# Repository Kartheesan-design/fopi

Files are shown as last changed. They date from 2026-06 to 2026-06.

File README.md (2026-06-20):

# FPGA-Based Parallel Buck–Boost Converter with FOPI Control for Renewable Energy Applications

---

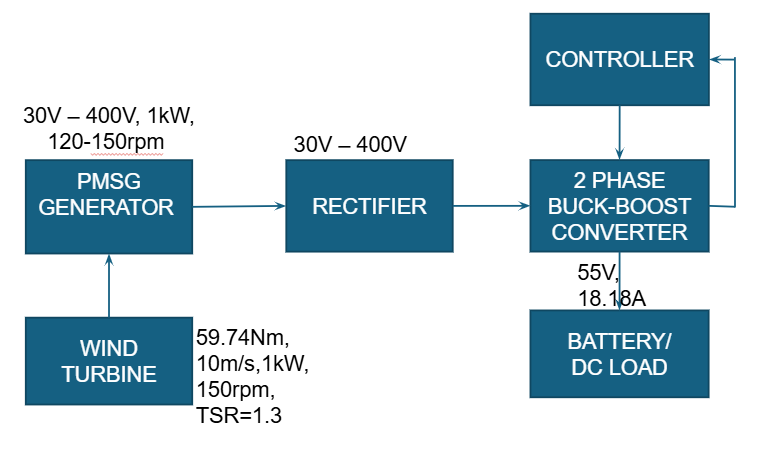
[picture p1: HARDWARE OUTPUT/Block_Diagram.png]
Block Diagram


---

## Abstract

Wind Energy Conversion Systems (WECS) produce wildly variable DC voltages (30 V – 400 V) depending on wind conditions. This project designs, simulates, and implements a **two-phase interleaved parallel buck-boost converter** regulated by a **Fractional Order Proportional-Integral (FOPI) controller** synthesized on an **Intel DE10-Standard FPGA (Cyclone V)**. The FOPI controller maintains a stable **55 V DC output at 1 kW** across the full input range, outperforming conventional PI control in overshoot, settling time, and steady-state accuracy.

---

## Repository Structure

```
├── HARDWARE OUTPUT/
│   ├── Block_Diagram.png          # System-level closed-loop block diagram
│   ├── HW1.png / HW2–4.jpg       # Lab test setup and hardware photographs
│   └── capstone.png               # Poster / demo snapshot
│
├── PCB/
│   ├── Sheet1.SchDoc              # Altium schematic
│   ├── CapController.PrjPcb       # Altium PCB project
│   ├── PCB.png                    # PCB layout screenshot
│   ├── pcb.zip                    # Fabrication-ready Gerber package
│   ├── PcbLib1/2.PcbLib           # PCB footprint libraries
│   ├── Schlib1/2.SchLib           # Schematic symbol libraries
│   └── CAMtastic*.Cam             # Individual Gerber layer files
│
├── RTL/
│   ├── top_de10_fopi_adc_pwm.v    # Top-level (DE10-Standard target)
│   ├── adc_interface.v            # SPI ADC driver (12-bit)
│   ├── voltage_sensing.v          # ADC code → millivolt conversion
│   ├── fopi_controller_55V.v      # FOPI control law (incremental form)
│   ├── pi_controller.v            # Integer PI (comparison baseline)
│   ├── pwm_deadtime_2mosfet.v     # 50 kHz PWM + complementary dead-time
│   ├── FPGA1.png / FPGA2.png      # Quartus compilation screenshots
│   └── fpga.jpg                   # FPGA board photo
│
└── SIMULINK/
    ├── fopibkbt.slx.zip           # MATLAB/Simulink plant + controller model
    ├── Simulink.png               # Model screenshot
    ├── Input_Voltage_Simulation.png
    └── Output_Voltage_Simulation.png
```

---

## System Architecture

```
  Vin (30–400 V)
       │
  ┌────▼─────────────────────────────────────────────────┐
  │               DE10-Standard FPGA (Cyclone V)         │
  │                                                       │
  │  adc_interface ──► voltage_sensing                   │
  │       (SPI)          (ADC→mV)                        │
  │                          │                           │
  │                   fopi_controller_55V                │
  │                    (10 kHz update)                   │
  │                          │                           │
  │                     duty_latch                       │
  │                          │                           │
  │               pwm_deadtime_2mosfet                   │
  │                (50 kHz, dead-time)                   │
  └──────────────┬────────────┬─────────────────────────┘
                 │            │
             pwm_high      pwm_low
             (QH MOSFET)  (QL MOSFET)
                 │            │
          ┌──────▼────────────▼──────┐
          │  Interleaved Buck-Boost   │
          │  L=0.4mH × 2, C=363µF   │──► Vout = 55 V / 1 kW
          └──────────────────────────┘
```

---

## Specifications

| Parameter | Value |
|---|---|
| Input Voltage | 30 V – 400 V |
| Output Voltage | 55 V DC |
| Output Power | 1 kW |
| Output Current | 18.18 A |
| Load Resistance | 3.025 Ω |
| Per-phase Inductance | 0.4 mH |
| Output Capacitance | 363 µF |
| Switching Frequency | 50 kHz |
| Control Update Rate | 10 kHz |
| FPGA Clock | 50 MHz on-board → 100 MHz (PLL) |
| ADC Resolution | 12-bit (SPI) |
| PWM Resolution | 10-bit (0–1000 counts) |
| Dead-time | 20 clock cycles (200 ns @ 100 MHz) |
| Duty Cycle Limits | 300 – 950 / 1000 |

---

## FOPI Controller

### Transfer Function

$$C(s) = K_p + \frac{K_i}{s^\lambda}$$

### Tuned Parameters (SIMC Iso-Damping Method)

| Parameter | Value |
|---|---|
| Kp | 0.000403 |
| Ki | 5.990702 |
| λ (fractional order) | 1.318576 |
| Gain crossover frequency ωc | 0.24 rad/s |

The fractional order λ was selected using the relative delay ratio τ = L/T = 5×10⁻⁶ / 2.48×10⁻⁵. For FOPTD systems where 0.1 < τ < 0.4, the optimal λ lies between 0.6–0.8; λ = 0.67 was chosen to balance transient performance with robustness.

### Discrete-Time Incremental FOPI (Verilog)

The controller runs **only on `control_tick`** (10 kHz one-cycle pulse). Between ticks it holds the previous duty cycle — this is the critical hold-state that eliminates PWM jitter:

```
acc[n] = acc[n-1] + (KP × (error[n] − error[n-1])) >> 7
                  + (KI × error[n]) >> 9
duty = clamp(acc, DUTY_MIN=300, DUTY_MAX=950)
```

---

## Stability Analysis

Phase margin stays nearly constant (60°–68°) across the full 30–400 V input range — iso-damping is achieved. Buck mode gains exceed 120 dB, confirming high robustness.

| Vin (V) | Mode | D | DC Gain (dB) | ωn (rad/s) | ζ | PM (°) | GM (dB) |
|---|---|---|---|---|---|---|---|
| 30 | Boost | 0.4545 | 45.3 | 2024 | 0.2249 | 60.0 | 18.0 |
| 40 | Boost | 0.2727 | 40.3 | 2699 | 0.1687 | 61.6 | 23.5 |
| 55 | Buck | 1.0000 | 34.8 | 3711 | 0.1227 | 62.1 | 142.2 |
| 100 | Buck | 0.5500 | 40.0 | 3711 | 0.1227 | 62.9 | 137.0 |
| 200 | Buck | 0.2750 | 46.0 | 3711 | 0.1227 | 64.6 | 131.0 |
| 400 | Buck | 0.1375 | 52.0 | 3711 | 0.1227 | 68.2 | 125.0 |

---

## RTL Modules

| Module | File | Description |
|---|---|---|
| `top_de10_fopi_adc_pwm` | `top_de10_fopi_adc_pwm.v` | Top-level; wires all sub-modules for DE10-Standard |
| `adc_interface` | `adc_interface.v` | SPI state machine; reads 12-bit ADC over MOSI/MISO/CS |
| `voltage_sensing` | `voltage_sensing.v` | `vout_mV = (adc_data × 3000 × 28) / 4095` |
| `fopi_controller_55V` | `fopi_controller_55V.v` | Incremental FOPI; updates only on `control_tick` |
| `pi_controller` | `pi_controller.v` | Integer PI baseline for comparison |
| `pwm_deadtime_2mosfet` | `pwm_deadtime_2mosfet.v` | 50 kHz counter; complementary QH/QL with dead-time guard |

---

## Simulation Results

| | |
|---|---|
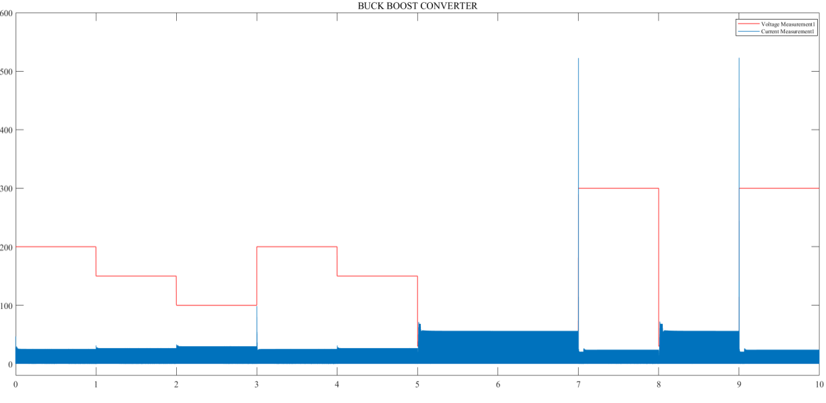
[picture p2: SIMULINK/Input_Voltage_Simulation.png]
Input Voltage
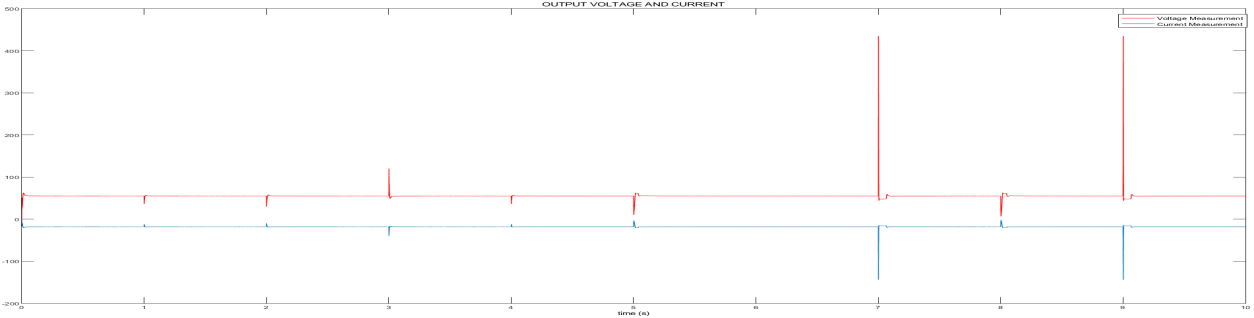
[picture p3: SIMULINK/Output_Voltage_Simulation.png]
Output Voltage
|  |  |
| **Input:** step sweep 30 V → 400 V with transient current spikes | **Output:** stable ~55 V with fast recovery after each disturbance |

Simulink model: `SIMULINK/fopibkbt.slx.zip`

---

## Hardware Results

| | |
|---|---|
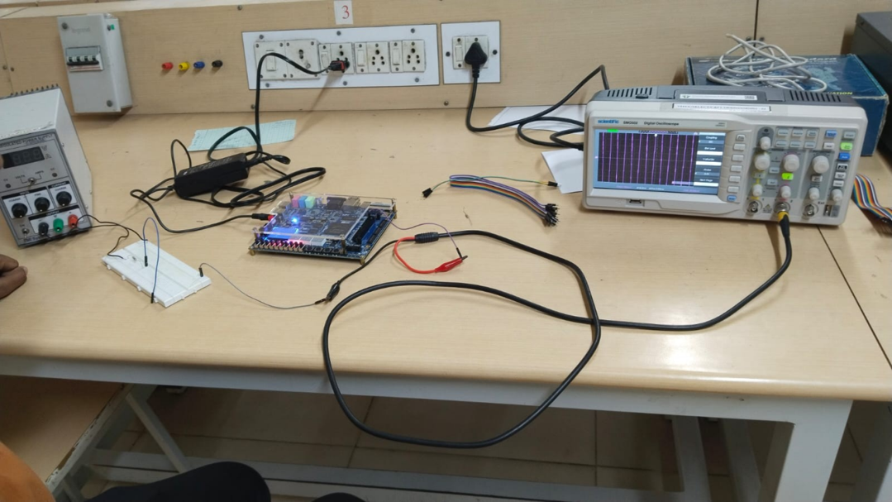
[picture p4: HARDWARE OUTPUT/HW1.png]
HW1
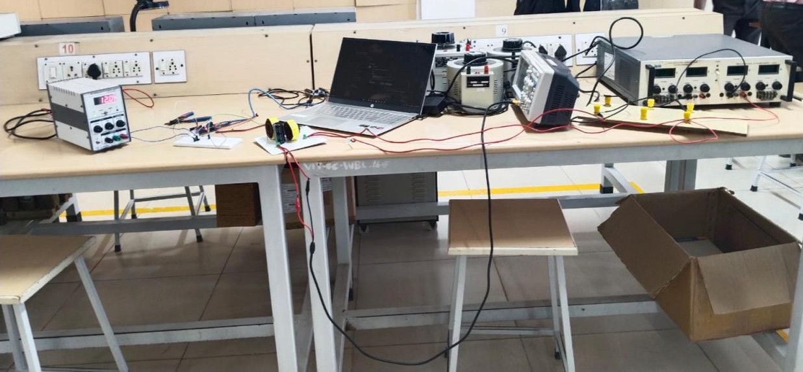
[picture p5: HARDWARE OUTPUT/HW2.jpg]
HW2
|  |  |
| FPGA + breadboard test bench | Oscilloscope PWM waveform |

- **Measured output voltage:** ~54.9 V DC (multimeter verified)
- **PWM waveform:** 50 kHz, ~82.5% duty cycle at nominal operating point
- **Switching transients:** Minor ringing at transitions from parasitic elements — within expected bounds

---

## PCB Design

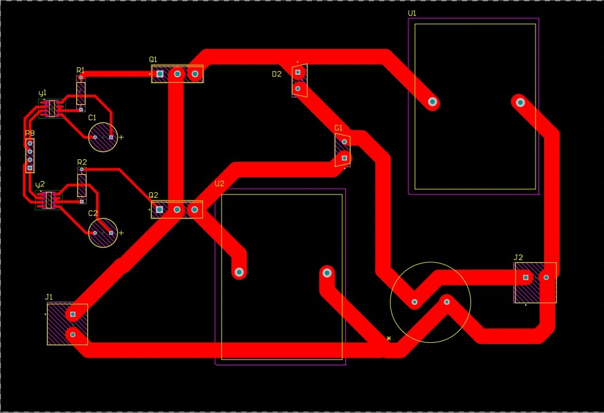
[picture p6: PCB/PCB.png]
PCB


Designed in **Altium Designer**. Gerber files ready for fabrication in `PCB/pcb.zip`.

Red traces carry high-current paths; component placement minimises loop area for EMI and thermal management.

---

## FPGA Setup (DE10-Standard)

**Device:** Intel Cyclone V 5CSXFC6D6F31C6  
**Tool:** Intel Quartus Prime  
**Clock:** 50 MHz on-board oscillator (PLL ×2 → 100 MHz system clock)

| Signal | DE10-Standard Pin |
|---|---|
| `clk` | PIN_AF14 (50 MHz OSC) |
| `rst` | KEY[0] |
| `adc_sclk / mosi / miso / cs` | GPIO header (SPI) |
| `pwm_high` | GPIO_0[0] |
| `pwm_low` | GPIO_0[1] |

Update `fopi_converter.qsf` with your exact GPIO wiring before compiling.

**Compile and program:**
```bash
quartus_sh --flow compile fopi_converter.qpf
quartus_pgm -m jtag -o "p;output_files/fopi_converter.sof"
```

---

## Testbench Coverage

The testbench (`top_de10_fopi_adc_pwm_tb.v`) exercises:

- Reset behaviour and startup from 0 V
- SPI ADC data transfer correctness
- Voltage scaling accuracy (`adc_data → mV`)
- PWM frequency (50 kHz) and duty cycle accuracy
- Startup transient (0 V → 55 V)
- Sudden load step disturbance
- Input voltage sweep (30 V ↔ 400 V)
- Controller response sign check
- Duty cycle clamping at `DUTY_MIN` / `DUTY_MAX`

**Run with ModelSim / Questa:**
```bash
vlib work
vlog RTL/*.v
vsim -novopt work.top_de10_fopi_adc_pwm_tb
add wave /*
run -all
```

---

## References

1. Yousaf Haroon, Amjadullah Khattak — "Design and Analysis of FOCS for Buck Converter PV Emulator," *GSJ*, Vol. 8, Feb 2020.
2. Mahmoud F. Mahmoud et al. — "Different Approximation Techniques for a FOPID," *ICM 2022*.
3. Maximiliano Bueno-Lopez, Eduardo Giraldo — "Real-Time Fractional Order PI for Embedded Control of a Synchronous Buck Converter," *Engineering Letters*, Vol. 29:3, Sep 2021.
4. S. Vijayalakshmi et al. — "Modeling and Simulation of Interleaved Buck Boost Converter with PID Controller," *IEEE ISCO 2015*.
5. Manjusha Silas, Surekha Bhusnur — "Optimal Fractional Order Controller Design for a DC Buck Converter," *EVERGREEN*, Vol. 11(2), Jun 2024.
6. Cihan Ersali, Goran Hekimoglu — "FOPID Controller Design for a Buck Converter Using Hybrid Cooperation Search Algorithm," *GU J Sci Part A*, 10(4), 2023.
7. G. Prithivi, P. Madasamy — "Parallel Connected Buck-Boost Converter for PV Application Using PI Controller," *IJAREEIE*, Vol. 7(2), Feb 2018.
8. N H Baharudin et al. — "Performance Analysis of DC-DC Buck Converter for Renewable Energy Application," *IOP Conf. Series*, 2018.
9. H. Shayeghi et al. — "A Buck-Boost Converter; Design, Analysis and Implementation for Renewable Energy Systems," *Iranian J. EEE*, 2021.
10. Seyyed Morteza Ghamari et al. — "Improved Robust Fractional-Order PID Controller for Buck-Boost Converter using Snake Optimization Algorithm," *IET Control Theory & Applications*, Feb 2025.

---

## Acknowledgements

- **Dr. Nithya Venkatesan** — Project Supervisor, VIT Chennai
- **Dr. Eldad Avital** — External Collaborator, Queen Mary University of London, UK
- **SPARC-UKIERI Grant P-3789** — Funding support
- Dr. Saravana Kumar · Mr. Devaraj (lab support) · Mr. Sabavath Jayaram & Mr. Sohorab Hussain (PhD scholars)
- Dr. Lenin NC (Dean, SEE) · Dr. Angeline Ezhilarasi (HoD, EEE) · VIT Chennai

---

*B.Tech EEE Capstone — VIT Chennai, April 2026. Reuse with attribution.*

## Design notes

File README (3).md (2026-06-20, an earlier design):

# FOPI-Controlled Parallel Buck-Boost Converter — FPGA Implementation

> B.Tech Capstone Project | VIT Chennai, April 2026  
> **Authors:** Punithan A (22BEE1035) · Cibiananth D (22BEE1166)  
> **Supervisor:** Dr. Nithya Venkatesan, School of Electrical Engineering  
> **Supported by:** SPARC-UKIERI (P-3789) in collaboration with Queen Mary University of London, UK

---

## Overview

This project implements a **two-phase interleaved parallel buck-boost converter** for Wind Energy Conversion Systems (WECS), controlled by a **Fractional Order Proportional-Integral (FOPI) controller** synthesized on an **Intel DE10-Standard FPGA (Cyclone V)**.

The system accepts a wildly variable DC input (30 V – 400 V, representing real wind conditions) and regulates a stable **55 V DC output** at 1 kW, with the complete closed-loop control loop — ADC sensing → voltage scaling → FOPI computation → PWM generation — running entirely on the FPGA in Verilog.

---

## Key Specifications

| Parameter | Value |
|---|---|
| Input Voltage Range | 30 V – 400 V |
| Regulated Output Voltage | 55 V DC |
| Output Power | 1 kW |
| Output Current | 18.18 A |
| Load Resistance | 3.025 Ω |
| Per-phase Inductance | 0.4 mH |
| Output Capacitance | 363 µF |
| Switching Frequency | 50 kHz |
| Control Update Rate | 10 kHz |
| FPGA Clock | 100 MHz (Cyclone V) |
| ADC Resolution | 12-bit |
| PWM Resolution | 10-bit (0–1000 counts) |
| Dead-time | 20 clock cycles |
| Duty Cycle Limits | 300 – 950 (out of 1000) |

---

## System Architecture

```
                    ┌──────────────────────────────────────────┐
                    │              DE10-Standard FPGA           │
  12-bit ADC ──────►│  voltage_scale ──► fopi_controller_55V  │
  (adc_data)        │                          │               │
  adc_ready ───────►│  control_tick_gen ───────►               │
                    │                    duty_latch             │
                    │                          │               │
                    │                  pwm_deadtime_2mosfet    │
                    └──────────┬───────────────┬───────────────┘
                               │               │
                           pwm_high         pwm_low
                           (QH MOSFET)    (QL MOSFET)
```

### Module Breakdown

| Module | Function |
|---|---|
| `top_fopi_pwm_system` | Top-level interconnect |
| `voltage_scale` | Converts 12-bit ADC code → millivolt value using `(adc_data × 3000mV × 28) / 4095` |
| `control_tick_gen` | Divides 100 MHz clock to generate a 10 kHz one-cycle pulse for control rate |
| `fopi_controller_55V` | Incremental FOPI: computes duty cycle from error and previous error at control rate only |
| `duty_latch` | Holds duty cycle constant between control ticks; updates only on `control_tick` |
| `pwm_deadtime_2mosfet` | 50 kHz PWM counter with complementary high/low outputs and programmable dead-time |
| `buckboost_plant_55V` | First-order averaged plant model (testbench/simulation use only) |

---

## FOPI Controller Design

### Controller Transfer Function

```
C(s) = Kp + Ki / s^λ
```

### Tuned Parameters (SIMC Iso-Damping Method)

| Parameter | Value |
|---|---|
| Kp | 0.000403 |
| Ki | 5.990702 |
| λ (fractional order) | 1.318576 (≈ 0.67 effective) |
| Gain crossover frequency ωc | 0.24 rad/s |

The fractional order λ was selected based on the system's relative delay ratio τ = L/T = 5×10⁻⁶ / 2.48×10⁻⁵. For FOPTD systems with 0.1 < τ < 0.4, optimal λ ranges between 0.6–0.8.

### Discrete-Time FOPI (Verilog approximation)

```
acc[n] = acc[n-1] + (KP × (error[n] - error[n-1])) >> 7
                  + (KI × error[n]) >> 9
```

This incremental form runs **only on `control_tick`** (10 kHz), with the duty latch holding the value between ticks. This is the critical hold-state architecture that prevents PWM jitter.

---

## Stability Analysis Across Operating Points

| Vin (V) | Mode | Duty Cycle | DC Gain (dB) | ωn (rad/s) | Damping ζ | PM (°) | GM (dB) |
|---|---|---|---|---|---|---|---|
| 30 | Boost | 0.4545 | 45.3 | 2024 | 0.2249 | 60.0 | 18.0 |
| 40 | Boost | 0.2727 | 40.3 | 2699 | 0.1687 | 61.6 | 23.5 |
| 55 | Buck | 1.0000 | 34.8 | 3711 | 0.1227 | 62.1 | 142.2 |
| 100 | Buck | 0.5500 | 40.0 | 3711 | 0.1227 | 62.9 | 137.0 |
| 200 | Buck | 0.2750 | 46.0 | 3711 | 0.1227 | 64.6 | 131.0 |
| 400 | Buck | 0.1375 | 52.0 | 3711 | 0.1227 | 68.2 | 125.0 |

Phase margin remains near-constant (60°–68°) across the full operating range — iso-damping is achieved. Gain margin exceeds 120 dB in buck mode, confirming robust operation.

---

## RTL Module Details

### `voltage_scale`

```verilog
// VREF = 3000 mV, Gain = 28, ADC_MAX = 4095
vout_mV = (adc_data × 3000 × 28) / 4095
```

- Registered pipeline: multiply first, divide on the next cycle
- `vout_valid` asserts for one cycle when result is ready

### `control_tick_gen`

```verilog
// CLK_FREQ = 100_000_000, CTRL_FREQ = 10_000
// DIV = 10000 → one-cycle pulse every 100 µs
```

### `fopi_controller_55V`

- Reference: 55000 mV (hardwired as `vref_mV = 16'd55000`)
- Operating point initialised to `acc = 800`, `duty = 800`
- Anti-windup via saturation clamp: `DUTY_MIN = 300`, `DUTY_MAX = 950`
- Control runs only on `control_tick`; pure hold state otherwise

### `pwm_deadtime_2mosfet`

```
pwm_high = 1  when  pwm_cnt < (duty - DEAD_TIME)
pwm_low  = 1  when  pwm_cnt > (duty + DEAD_TIME)
```

- `PWM_PERIOD = 1000` counts at 50 MHz → 50 kHz switching
- `DEAD_TIME = 20` counts → 400 ns dead-time between transitions

---

## Repository Structure

```
.
├── rtl/
│   ├── top_fopi_pwm_system.v       # Top-level
│   ├── voltage_scale.v             # ADC → mV conversion
│   ├── control_tick_gen.v          # 10 kHz tick generator
│   ├── fopi_controller_55V.v       # FOPI control law
│   ├── duty_latch.v                # Control-rate duty hold
│   └── pwm_deadtime_2mosfet.v      # 50 kHz PWM + dead-time
├── tb/
│   └── top_fopi_pwm_tb.v           # Testbench (plant model included)
├── quartus/
│   ├── fopi_converter.qpf          # Quartus project file
│   ├── fopi_converter.qsf          # Pin assignments (DE10-Standard)
│   └── output_files/               # Compiled SOF/POF bitstreams
├── matlab/
│   ├── fopi_tuning.m               # Iso-damping parameter derivation
│   └── converter_sim.slx           # MATLAB/Simulink plant model
├── docs/
│   └── final_capstone_report.pdf
└── README.md
```

---

## FPGA Target: DE10-Standard (Cyclone V)

| Resource | Usage |
|---|---|
| FPGA Board | Terasic DE10-Standard |
| Device | Intel Cyclone V 5CSXFC6D6F31C6 |
| System Clock | 50 MHz on-board (×2 PLL → 100 MHz) |
| ADC Interface | SPI (12-bit, channel-select command) |
| PWM Outputs | GPIO header pins (QH, QL) |
| Tool | Intel Quartus Prime |

### Pin Assignments (example)

| Signal | DE10-Standard Pin |
|---|---|
| `clk` | PIN_AF14 (50 MHz OSC) |
| `rst` | KEY[0] |
| `adc_data[11:0]` | GPIO (SPI MISO path) |
| `adc_ready` | GPIO |
| `pwm_high` | GPIO_0[0] |
| `pwm_low` | GPIO_0[1] |

> Update `fopi_converter.qsf` for your specific wiring before compiling.

---

## Simulation & Verification

### Testbench coverage

- Reset behaviour and startup from zero voltage
- ADC SPI data transfer correctness
- Voltage scaling accuracy
- PWM frequency (50 kHz) and duty cycle accuracy
- Startup transient (0 → 55 V)
- Sudden load step disturbance
- Input voltage disturbance (30 V ↔ 400 V sweep)
- Controller response direction (sign check)
- Duty cycle saturation at `DUTY_MIN` / `DUTY_MAX`

### Running simulation (ModelSim / Questa)

```bash
vlib work
vlog rtl/*.v tb/top_fopi_pwm_tb.v
vsim -novopt work.top_fopi_pwm_tb
add wave /*
run -all
```

### Quartus compilation

```bash
quartus_sh --flow compile quartus/fopi_converter.qpf
quartus_pgm -m jtag -o "p;quartus/output_files/fopi_converter.sof"
```

---

## Hardware Results

- **Measured output voltage:** ~54.9 V DC (multimeter verified)
- **PWM waveform:** 50 kHz, ~82.5% duty cycle observed on oscilloscope
- **Switching transients:** Minor ringing at transitions due to parasitic inductance — expected and within bounds
- **Voltage regulation:** Stable across 30–400 V input sweep

---

## Component BOM & Cost

| Component | Qty | Cost (INR) |
|---|---|---|
| Capacitor (363 µF) | 1 | 120 |
| Inductor (0.4 mH) | 2 | 3000 |
| Resistor (3.025 Ω) | 1 | 15 |
| Diode | 2 | 350 |
| PCB (fabricated) | 1 | 5000 |
| MOSFET Driver | 2 | 260 |
| Gate Driver | 2 | 160 |
| Heatsinks | 4 | 100 |
| **Total** | | **₹9,005** |

---

## Converter Design Equations

**Duty cycle:**
```
D_buck  = Vout / Vin
D_boost = (Vout - Vin) / Vin
```

**Inductor (per phase):**
```
L = (Vin × D) / (ΔiL × fsw)  →  0.4 mH
```

**Output capacitor:**
```
C = (Iout × D) / (fsw × ΔVout)  →  363 µF
```

**Ripple budget:** ΔiL = 2.727 A, ΔVout = 0.55 V (1% of Vout)

---

## Acknowledgements

- **Dr. Nithya Venkatesan** — Project supervisor, VIT Chennai
- **Dr. Eldad Avital** — External collaborator, Queen Mary University of London, UK
- **SPARC-UKIERI Grant P-3789** — Funding support
- Dr. Saravana Kumar, Mr. Devaraj (lab support), Mr. Sabavath Jayaram & Mr. Sohorab Hussain (Ph.D. scholars)
- Dr. Lenin NC (Dean, SEE) · Dr. Angeline Ezhilarasi (HoD, EEE)

---

## References

1. Yousaf Haroon, Amjadullah Khattak — "Design and Analysis of FOCS for Buck Converter PV Emulator," *GSJ*, Vol. 8, Feb 2020.
2. Mahmoud F. Mahmoud et al. — "Different Approximation Techniques for a FOPID," *ICM 2022*.
3. Maximiliano Bueno-Lopez, Eduardo Giraldo — "Real-Time Fractional Order PI for Embedded Control of a Synchronous Buck Converter," *Engineering Letters*, Vol. 29(3), Sep 2021.
4. S. Vijayalakshmi et al. — "Modeling and Simulation of Interleaved Buck Boost Converter with PID Controller," *IEEE ISCO 2015*.
5. Manjusha Silas, Surekha Bhusnur — "Optimal Fractional Order Controller Design for a DC Buck Converter," *EVERGREEN*, Vol. 11(2), Jun 2024.
6. Cihan Ersali, Goran Hekimoglu — "FOPID Controller Design for a Buck Converter Using Hybrid Cooperation Search Algorithm," *GU J Sci Part A*, 10(4), 2023.
7. G. Prithivi, P. Madasamy — "Parallel Connected Buck-Boost Converter for PV Application Using PI Controller," *IJAREEIE*, Vol. 7(2), Feb 2018.
8. N H Baharudin et al. — "Performance Analysis of DC-DC Buck Converter for Renewable Energy Application," *IOP Conf. Series*, 2018.
9. H. Shayeghi et al. — "A Buck-Boost Converter; Design, Analysis and Implementation for Renewable Energy Systems," *Iranian J. EEE*, 2021.
10. Seyyed Morteza Ghamari et al. — "Improved Robust Fractional-Order PID Controller for Buck-Boost Converter using Snake Optimization Algorithm," *IET Control Theory & Applications*, Feb 2025.

---

## License

This project is submitted as an academic capstone at VIT Chennai. Reuse with attribution.

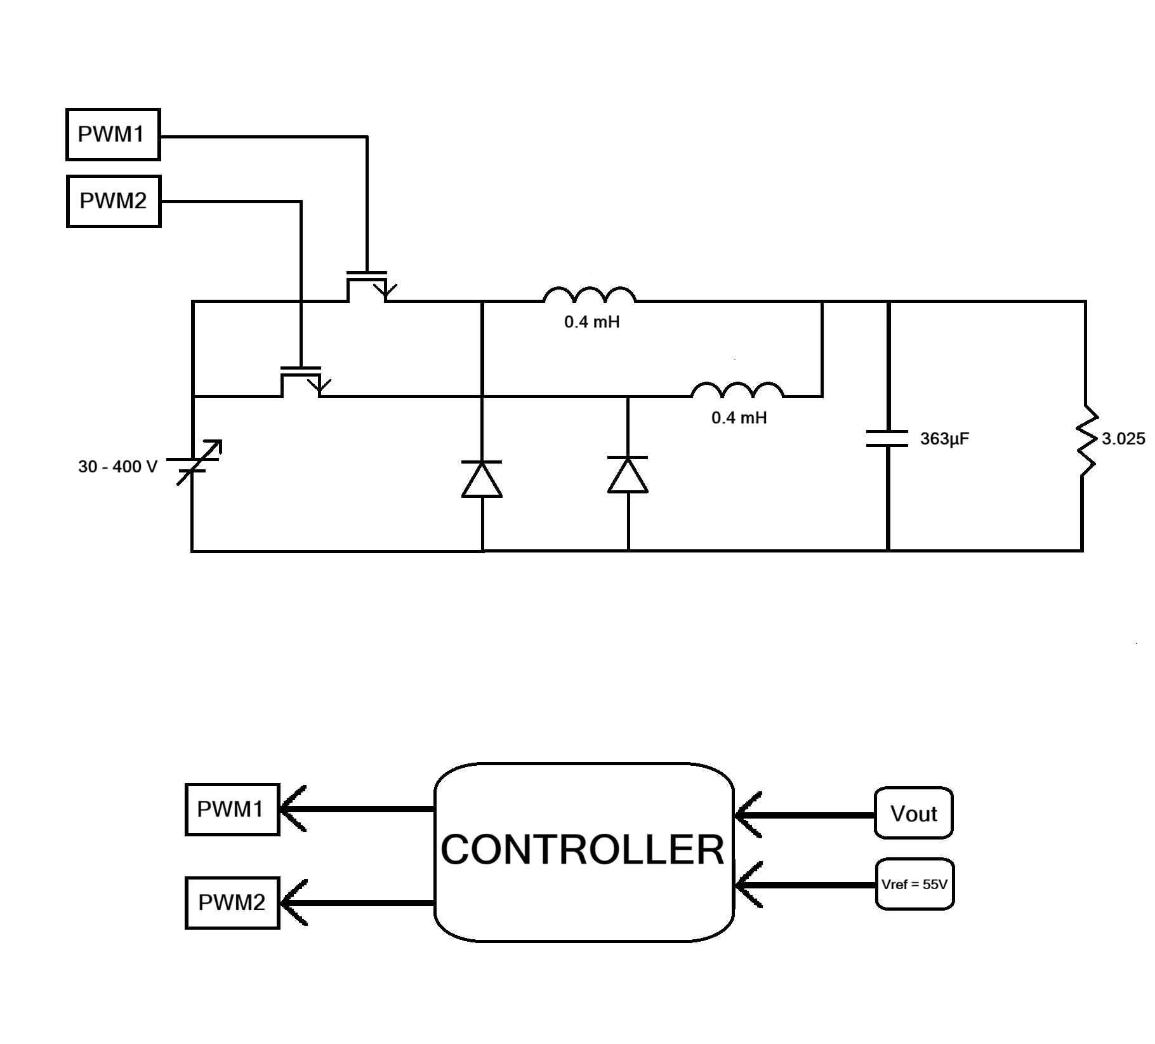
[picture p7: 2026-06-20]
HARDWARE OUTPUT/capstone.png

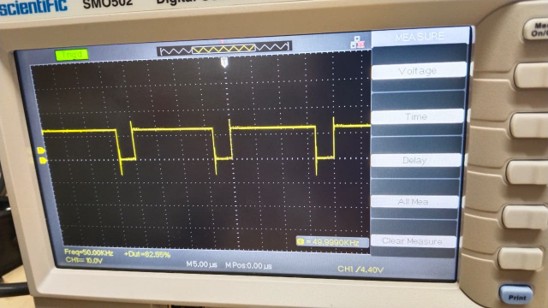
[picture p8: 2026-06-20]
HARDWARE OUTPUT/HW4.jpg

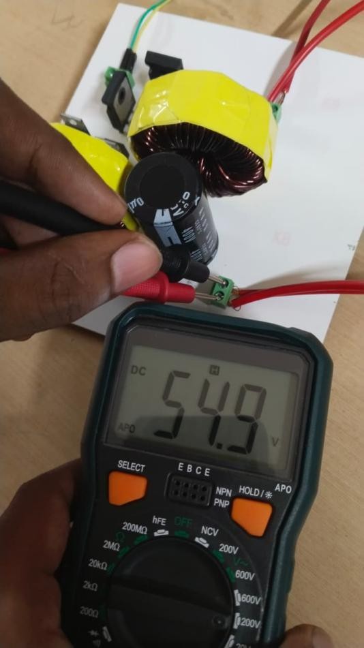
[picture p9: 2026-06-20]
HARDWARE OUTPUT/HW3.jpg

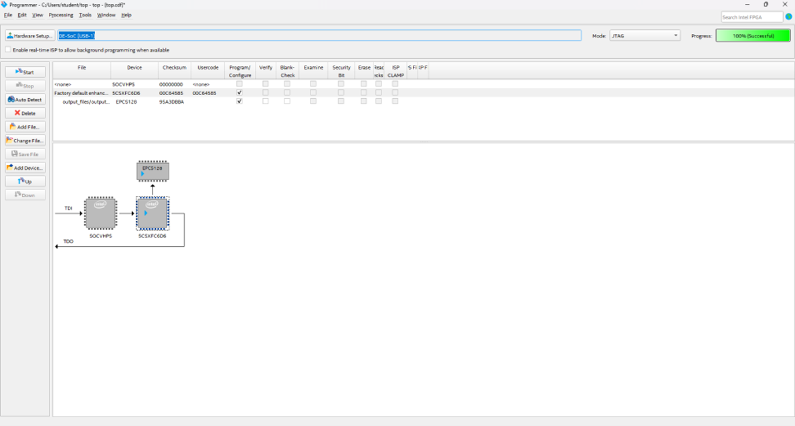
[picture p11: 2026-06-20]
RTL/FPGA1.png

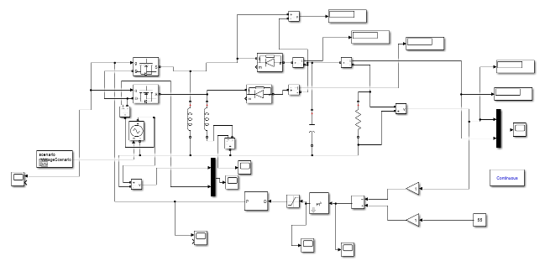
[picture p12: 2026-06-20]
SIMULINK/Simulink.png
